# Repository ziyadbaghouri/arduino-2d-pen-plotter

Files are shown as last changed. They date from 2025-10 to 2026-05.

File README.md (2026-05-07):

# Arduino 2D Pen Plotter

A compact two-axis **Arduino-driven pen plotter** that draws shapes and text on paper using two stepper motors, timing belts, and a servo-controlled pen-lifting mechanism.

This project was developed as the **Individual Project** for the EPFL “Making Intelligent Things” course (Spring 2025).  
It combines **mechanical design (CAD + laser cutting + 3D printing)** with **embedded control programming** on Arduino.

---

## Overview

The 2D Plotter translates digital drawings into physical motion through:
- **Two orthogonal linear axes** (X and Y) driven by 28BYJ-48 stepper motors via GT2 belts,  
- A **servo-actuated pen holder** for lift/lower control, and  
- An **Arduino Uno** that synchronizes both movements using the AccelStepper library.

---

## Hardware Architecture

| Category | Component | Function |
|---|---|---|
| **Microcontroller** | Arduino Uno | Central controller for motion and servo commands |
| **Motors** | 2 × 28BYJ-48 5 V steppers | Drive X- and Y-axis movement |
| **Motor Drivers** | 2 × ULN2003 boards | Control signals from the Uno to the stepper coils |
| **Servo** | SG90 9 g servo | Raises and lowers the pen |
| **Transmission** | 2 × GT2 belts (40 cm & 62 cm) + 2 × GT2 pulleys (5 mm) | Belt-driven linear motion |
| **Structure** | Combination of laser-cut MDF parts and 3D-printed PETG components | Provides a stable and lightweight frame |
| **Power** | 5 V USB breakout board + micro-USB cable | Dedicated supply for motors and servo |

All grounds are common between Arduino, stepper drivers, and servo.  
External 5 V power avoids overloading the Arduino’s regulator.

---

## Mechanical Design

The complete mechanical assembly is provided in [`/cad/design.step`](cad/design.step).

The pen holder uses a **spring-loaded sliding design**:  
when the servo moves down, the pen holder can **slide backward slightly** against the spring tension.  
This prevents excessive pressure on the pen tip and protects the servo gears from overload, ensuring smoother contact with the paper surface and more consistent line thickness during plotting.

---

## Electronics Diagram

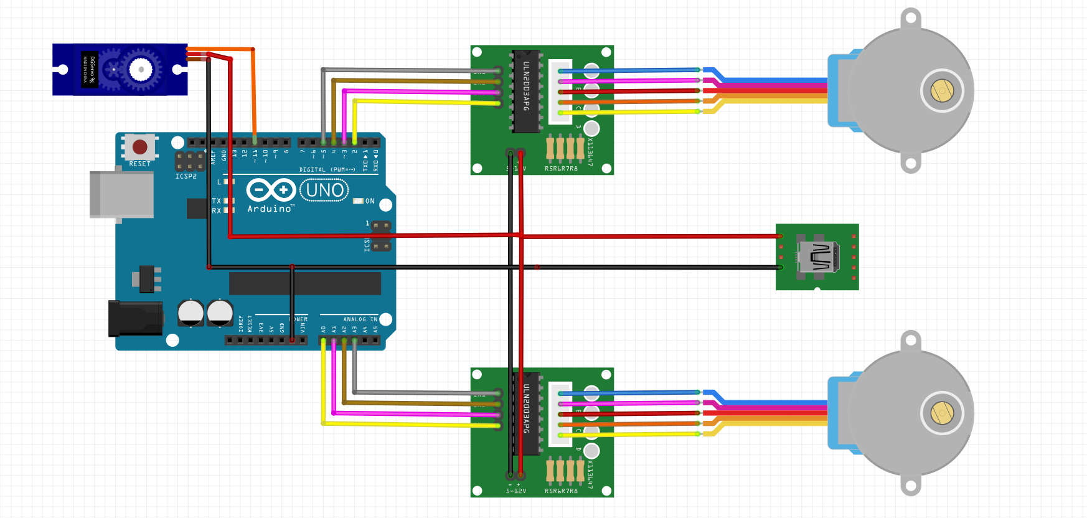
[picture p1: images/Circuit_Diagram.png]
Wiring diagram
  
---

## Programming Assignment 1 — Square and Inscribed Circle

This is the **first programming assignment implemented for the Arduino 2D Pen Plotter project**.  
Its goal is to verify the synchronization of both stepper motors and demonstrate precise two-axis motion by drawing a **square followed by an inscribed circle**.

The code uses the [AccelStepper](https://www.airspayce.com/mikem/arduino/AccelStepper/) library in **FULL4WIRE mode** to drive two 28BYJ-48 motors via ULN2003 driver boards.  

| Section | Purpose |
|---|---|
| **Config** | Defines motion parameters such as steps per side (`SIDE_STEPS = 4000`), motor directions (`DIR_X`, `DIR_Y`), and motion tuning (`MAX_SPEED`, `ACCEL`). |
| **Motors setup** | Two `AccelStepper` objects are created—one for each axis—with pins matching the ULN2003 driver connections. |
| **`moveToXY_blocking()`** | Core function that performs synchronized absolute moves by calling `X.run()` and `Y.run()` until both reach target positions. |
| **`setup()`** | Initializes motors, sets speed/acceleration, resets positions, and executes the entire motion sequence: a square followed by an inscribed circle. |
| **`loop()`** | Empty — all drawing occurs once during setup. |

---

## Programming Assignment 2 — Autopen Text Writing in D’Nealian Cursive

This is the **final programming assignment** of the “Making Intelligent Things” project.  
The task, as specified in the course handout, was to **create an autopen program** that writes text typed into the Arduino IDE **Serial Monitor** in *D’Nealian cursive*.

The implementation supports:
- **At least 15 lowercase letters** (`d e f h k l m n p r t u v w x`) - we can easily add the other letters.
- **Whitespace** and **line breaks**
- Up to 40 characters total per console input, with line wrapping after 7 characters

Letters in each word are **smoothly connected**, and the **pen lifts** between strokes (such as for ‘i’ or ‘x’) to mimic real cursive handwriting.

This assignment combines every subsystem of the plotter:
| Module | Description |
|---|---|
| **Stepper control** | Handles synchronized XY movement for precise character tracing |
| **Servo actuation** | Lifts or lowers the pen between strokes (`penUp()` / `penDown()`) |
| **Serial interface** | Receives characters from Serial Monitor input |
| **Font data** | Stored in [`letters_all.h`](code/letters_all.h) — coordinate arrays extracted from SVG letters |
| **Plot logic** | Converts SVG units to stepper steps with calibrated scale and spacing |

---

### SVG → Arduino Pipeline

1. A Python utility [`extract_letters_batch.py`](code/extract_letters_batch.py) converts vector paths from a reference SVG alphabet into arrays of (x, y) coordinates.
2. The raw coordinates were **manually adjusted and rescaled** to align all glyphs on a common baseline and spacing — resulting in the final [`letters_all.h`](code/letters_all.h) file.
3. The Arduino firmware reads these arrays from PROGMEM and draws them sequentially as the user types.

This fine-tuning ensures that **words appear evenly aligned and continuous** when drawn in one line, avoiding uneven jumps or overlaps between letters.

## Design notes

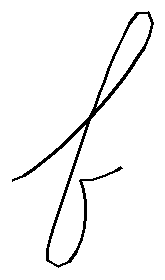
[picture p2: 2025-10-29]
code/draw_letters/png_out/letter_f.png

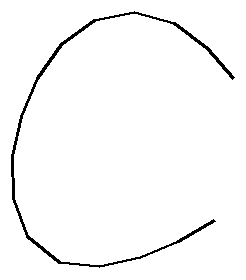
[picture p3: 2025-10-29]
code/draw_letters/png_out/letter_c.png

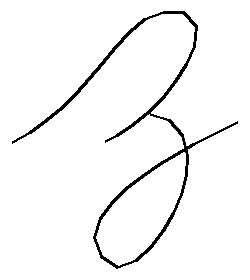
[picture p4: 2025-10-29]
code/draw_letters/png_out/letter_z.png

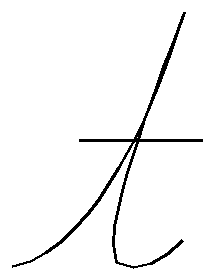
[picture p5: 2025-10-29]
code/draw_letters/png_out/letter_t.png

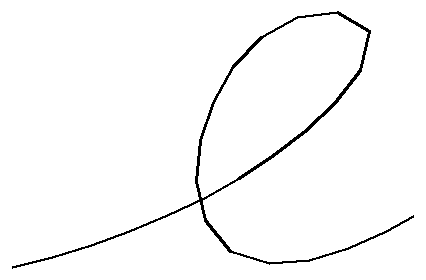
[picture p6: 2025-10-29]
code/draw_letters/png_out/letter_e.png

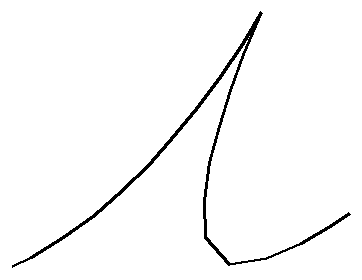
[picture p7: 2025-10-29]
code/draw_letters/png_out/letter_i.png

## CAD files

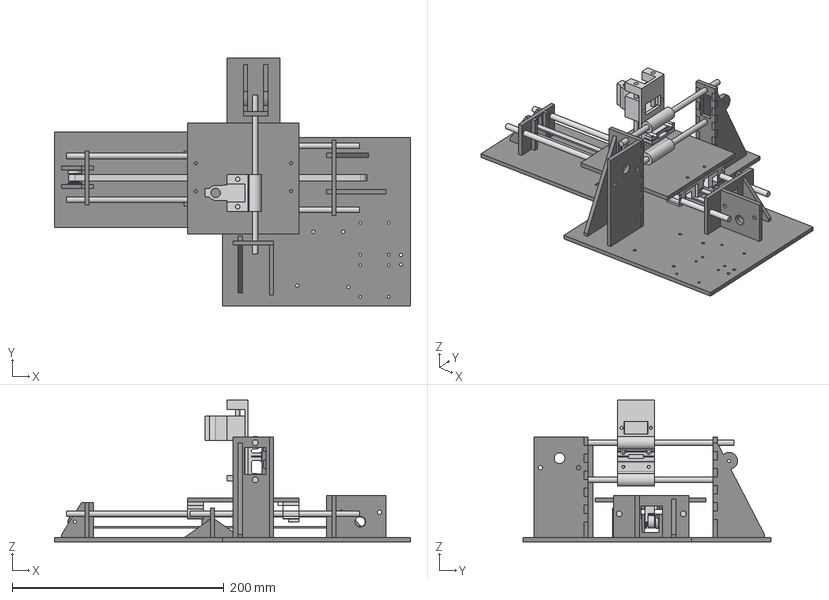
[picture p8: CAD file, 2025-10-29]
cad/design.step
336.0 x 234.0 x 133.8 mm
TopRailHolder
BottomRailHolder
RightRailHolder
LeftRailHolder
MiddleHolder
PlateHolderNarrow
BasePlankNew
PenHolderSlider
Draw plate
Belt
PlateHolderWide
BlindPulley
Nails

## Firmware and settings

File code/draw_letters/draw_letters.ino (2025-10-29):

#include <math.h>           // for NAN, isnan()
#include <ctype.h>          // for tolower()
#include <AccelStepper.h>
#include <Servo.h>
#include <avr/pgmspace.h>   // for progmem()


#include "letters_all.h"

#define MotorInterfaceType 8

// ---- CONFIG ----
const float LETTER_SCALE               = 12.0f;   // overall size scaler (steps per SVG unit)
const long  SPACE_STEPS                = 400;     // gap between words
const long  LINE_SPACE_STEPS           = 800;     // gap between lines
const int   NUM_CHAR_PER_LINE          = 7;      

const int DIR_X = -1;
const int DIR_Y = -1;

const float MAX_SPEED = 350.0f;      // steps/s
const float ACCEL     = 1000.0f;     // steps/s^2

const int SERVO_PIN       = 12;
const int PEN_UP_ANGLE    = 30;      
const int PEN_DOWN_ANGLE  = 0;       
const int PEN_SETTLE_MS   = 600;     

// ---- MOTORS ----
AccelStepper X(MotorInterfaceType, 8, 10, 9, 11);
AccelStepper Y(MotorInterfaceType, 2,  4, 3,  5);
Servo pen;

// Track where a line starts so we can wrap cleanly
long g_lineStartX = 0;
long g_lineStartY = 0;
int  g_charsOnLine = 0;

static bool  g_haveRef = false;
float g_refOx = 0.0f;   // fixed glyph-space origin X 
float g_refOy = 0.0f;   // fixed glyph-space origin Y


// ---- PEN ----
void penUp(){
   pen.write(PEN_UP_ANGLE);
   delay(PEN_SETTLE_MS); 
}

void penDown(){ 
  pen.write(PEN_DOWN_ANGLE);
  delay(PEN_SETTLE_MS); 
}

// ---- Move the pen ----
void moveToXY(long tx, long ty) {
  X.moveTo(tx);
  Y.moveTo(ty);
  while (X.distanceToGo() != 0 || Y.distanceToGo() != 0) {
    X.run();
    Y.run();
  }
}


// ---- Draw the letters ----
void drawLetter_P(const float (*letter)[2], int len, float SCALE) {
  // 1) Read this glyph's first point
  int i0 = 0;

  const float ox = pgm_read_float(&letter[i0][0]);
  const float oy = pgm_read_float(&letter[i0][1]);

  // 2) Lock a global glyph-space origin once (first letter only)
  if (!g_haveRef) {
    g_refOx = ox;
    g_refOy = oy;
    g_haveRef = true;
  }

  // 3) Compute per-glyph alignment so that THIS glyph's first point maps
  const long curX = X.currentPosition();
  const long curY = Y.currentPosition();
  const long startXAligned = curX - (long)lroundf((ox - g_refOx) * SCALE * DIR_X);
  const long startYAligned = curY - (long)lroundf((oy - g_refOy) * SCALE * DIR_Y);

  // 4) Draw all points with the fixed origin + aligned starts.
  bool needPenDown = false;

  // First point maps exactly to current position; the first move is a no-op.
  for (int i = i0; i < len; i++) {
    float px = pgm_read_float(&letter[i][0]);
    float py = pgm_read_float(&letter[i][1]);

    if (isnan(px) || isnan(py)) {
      // subpath break: lift; next valid point will move & pen back down
      penUp();
      needPenDown = true;
      continue;
    }

    const long tx = startXAligned + (long)lroundf((px - g_refOx) * SCALE * DIR_X);
    const long ty = startYAligned + (long)lroundf((py - g_refOy) * SCALE * DIR_Y);

    if (needPenDown) {
      moveToXY(tx, ty); // reposition to the new subpath start
      penDown();
      needPenDown = false;
    } else {
      penDown();
      moveToXY(tx, ty);
    }
  }
}



// ---- Make a space ----
void spaceStep() {
  moveToXY(X.currentPosition() + (long)(SPACE_STEPS) * DIR_X, Y.currentPosition());
}

// ---- Return to the line ----
void newLine() {
  penUp();
  moveToXY(X.currentPosition(), g_lineStartY + (long)LINE_SPACE_STEPS * (-1 * DIR_Y));
  moveToXY(g_lineStartX, Y.currentPosition());
  g_lineStartY = Y.currentPosition();    
  g_charsOnLine = 0;
}


// ---- Get coordinates from letter_all.h, to use letter switch to return true ----
bool getCoordinates(char c, const float (*&pts)[2], uint16_t &len) {
  c = tolower((unsigned char)c);
  switch (c) {
    case 'd': pts = letter_d; len = letter_d_len; return true;
    case 'e': pts = letter_e; len = letter_e_len; return true;
    case 'f': pts = letter_f; len = letter_f_len; return true;
    case 'h': pts = letter_h; len = letter_h_len; return true;
    case 'k': pts = letter_k; len = letter_k_len; return true;
    case 'l': pts = letter_l; len = letter_l_len; return true;
    case 'm': pts = letter_m; len = letter_m_len; return true;
    case 'n': pts = letter_n; len = letter_n_len; return true;
    case 'p': pts = letter_p; len = letter_p_len; return true;
    case 'r': pts = letter_r; len = letter_r_len; return true;
    case 't': pts = letter_t; len = letter_t_len; return true;
    case 'u': pts = letter_u; len = letter_u_len; return true;
    case 'v': pts = letter_v; len = letter_v_len; return true;
    case 'w': pts = letter_w; len = letter_w_len; return true;
    case 'x': pts = letter_x; len = letter_x_len; return true;
    default: return false;
  }
}

// ---- Serial Monitor input reader ----
void serialDrawHandler(float letterSize) {
  while (Serial.available() > 0) {
    char c = Serial.read();

    // Space is typed
    if (c == ' ') {
      spaceStep();
      if (++g_charsOnLine >= NUM_CHAR_PER_LINE) newLine();
      continue;
    }

    const float (*pts)[2]; uint16_t len;;
    if (getCoordinates(c, pts, len)) {
      drawLetter_P(pts, len, letterSize);
      if (++g_charsOnLine >= NUM_CHAR_PER_LINE) newLine();
    }
  }
}

// ---- SETUP ----
void setup() {
  Serial.begin(9600);

  X.enableOutputs(); Y.enableOutputs();
  X.setMaxSpeed(MAX_SPEED); Y.setMaxSpeed(MAX_SPEED);
  X.setAcceleration(ACCEL); Y.setAcceleration(ACCEL);
  X.setCurrentPosition(0);  Y.setCurrentPosition(0);

  pen.attach(SERVO_PIN);
  penUp();

  g_lineStartX = X.currentPosition();  // 0
  g_lineStartY = Y.currentPosition();  // 0       // baseline Y = 0
}

// ---- LOOP ----
void loop() {
  serialDrawHandler(LETTER_SCALE);
}

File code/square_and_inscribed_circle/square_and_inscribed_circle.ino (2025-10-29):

#include <AccelStepper.h>
#define MotorInterfaceType 8 

// ---- CONFIG ----
const long SIDE_STEPS = 4000;   // steps per side of the square
const int  DIR_X = -1;          // X axis direction 
const int  DIR_Y = -1;          // Y axis direction

const float MAX_SPEED = 350.0f; // steps/sec
const float ACCEL     = 1000.0f; // steps/sec^2
const int   SEGMENTS  = 150;    // circle segments 
// ---- motors ----
AccelStepper X(MotorInterfaceType, 8, 10, 9, 11);
AccelStepper Y(MotorInterfaceType, 2,  4, 3,  5);

// Move both axes to absolute targets (tx,ty) and block until both arrive.
void moveToXY_blocking(long tx, long ty) {
  X.moveTo(tx);
  Y.moveTo(ty);
  while (X.distanceToGo() != 0 || Y.distanceToGo() != 0) {
    X.run();
    Y.run();
  }
}

void setup() {
  Serial.begin(9600);
  delay(2000);

  // enable + configure
  X.enableOutputs(); Y.enableOutputs();
  X.setMaxSpeed(MAX_SPEED); Y.setMaxSpeed(MAX_SPEED);
  X.setAcceleration(ACCEL); Y.setAcceleration(ACCEL);
  X.setCurrentPosition(0);  Y.setCurrentPosition(0);

  // ---- Square start at (0,0) ----
  Serial.println(F("Start: draw square"));
  moveToXY_blocking(0, DIR_Y * (SIDE_STEPS / 2.0f)); // (0, -3000)
  moveToXY_blocking(DIR_X * SIDE_STEPS, DIR_Y * (SIDE_STEPS / 2.0f)); // (-6000, -3000)
  moveToXY_blocking(DIR_X * SIDE_STEPS, -DIR_Y * (SIDE_STEPS / 2.0f)); // (-6000, 3000)
  moveToXY_blocking(0, -DIR_Y * (SIDE_STEPS / 2.0f)); // (0, 3000)
  moveToXY_blocking(0,0); // (0, 0)
  Serial.println(F("Square done"));

  // circle center:
  const long cx = DIR_X * (SIDE_STEPS / 2.0f);
  const long cy = 0;

  // Inscribed circle radius 
  const long r = lround(SIDE_STEPS / 2.0f);

  // Draw circle
  Serial.println(F("Drawing circle"));
  const float theta0 = 0;
  for (int i = 0; i <= SEGMENTS; ++i) {
    float theta = theta0 + (TWO_PI * i) / SEGMENTS; 
    long tx = lround(cx + r * cos(theta));
    long ty = lround(cy + r * sin(theta));
    moveToXY_blocking(tx, ty);
  }
    Serial.println(F("Circle done"));
    X.disableOutputs(); Y.disableOutputs();
}

void loop() {
  // nothing: all work performed in setup()
}

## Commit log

2025-10-29 Add CAD design file
    [design.step]
2025-10-29 Add electronics circuit PDF schematic
2025-10-29 Update README.md
    Added details about the final programming assignment for creating an autopen program that writes in D’Nealian cursive, including implementation features and the SVG to Arduino pipeline.
